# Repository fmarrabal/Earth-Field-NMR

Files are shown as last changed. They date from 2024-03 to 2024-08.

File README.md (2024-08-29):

# Earth Field NMR Spectrometer

This repository contains the complete design, schematics, PCB layout, microcontroller firmware, and computer software for an Earth Field Nuclear Magnetic Resonance (EFNMR) spectrometer. This device is designed to operate using the Earth's magnetic field, providing a cost-effective and accessible NMR solution for educational and research purposes.

## Overview

Nuclear Magnetic Resonance (NMR) is a powerful analytical technique used to study the physical, chemical, and biological properties of matter. Conventional NMR spectrometers require high magnetic fields, making them expensive and limited to specialized laboratories. The Earth Field NMR (EFNMR) spectrometer, however, utilizes the Earth's magnetic field, significantly reducing the cost and complexity of the device.

This project aims to develop an EFNMR spectrometer that can be used for educational purposes, allowing students and researchers to gain hands-on experience with NMR technology without the need for high-field NMR equipment.

## Components

The EFNMR spectrometer consists of the following main components:

1. **Polarizing Coil**
   - Generates a temporary magnetic field to polarize the sample.
   - Specifications:
     - Enamelled copper wire: 1.7 mm or 14 AWG
     - Inner diameter: 80 mm
     - Outer diameter: 90 mm
     - Height: 145 mm
     - Approximate inductance: 3.4 mH
     - Approximate resistance: 0.8 Ω

2. **Receiver Coils (Antenna)**
   - Detects the signal from the polarized sample.
   - Specifications:
     - Enamelled copper wire: 0.812 mm or 21 AWG
     - Inner diameter: 25 mm
     - Outer diameter: 40 mm
     - Height: 100 mm
     - Approximate inductance per coil: 2.56 mH
     - Approximate resistance per coil: 2.5 Ω

3. **Power Circuit**
   - Controls the power supply to the polarizing coil.
   - Utilizes a MOSFET for fast switching and high current handling.

4. **Receiver Circuit**
   - Amplifies and filters the weak NMR signal from the receiver coils.
   - Consists of a low-noise instrumentation amplifier, additional amplification stages, and a band-pass filter.

5. **Microcontroller (STM32F373)**
   - Handles control tasks, signal digitization, and communication with a computer.
   - Features a 16-bit ADC and USB communication.

6. **Computer Software**
   - Provides a user interface for configuring experiments, visualizing results, and performing signal processing.
   - Developed in C# for ease of use and rapid implementation of new features.

## Usage

To use the EFNMR spectrometer, follow these steps:

1. **Assemble the Hardware**
   - Ensure all components are correctly assembled and connected as per the provided schematics and PCB layout.

2. **Upload the Firmware**
   - Program the STM32F373 microcontroller with the provided firmware.

3. **Install the Software**
   - Install the computer software on a compatible system.

4. **Perform an Experiment**
   - Use the software to configure the experimental parameters (e.g., number of samples, number of scans, pulse time).
   - Align the coils with the Earth's magnetic field using the built-in magnetometer.
   - Start the experiment and visualize the results in the software.

## Repository Contents

- `PCB/`: PCB layout files for manufacturing the PCBs.
- `Firmware/`: Source code for the microcontroller firmware.
- `EFMNR/`: Source code and binaries for the computer software.
- `Assembly/`: CAD designs for 3D printed parts used in the spectrometer assembly.

## Acknowledgements

This project was developed at the University of Almeria, Spain. Also, The research received generous funding from the following sources:
- the State Research Agency of the Spanish Ministry of Science and Innovation (PID2021-126445OB-I00)
- the Gobierno de España MCIN/AEI/10.13039 /501100011033
- European Union “Next Generation EU”/PRTR (PDC2021-121248-I00, PLEC2021- 007774 and CPP2022-009967).

We extend our heartfelt gratitude to all the contributors who played a vital role in making this project a reality.

## Reference

Please cite this project using the following BibTeX entry:

@article{Viciana2024,
author = {Viciana, Eduardo and Mart{\'{i}}nez-Lao, Juan Antonio and L{\'{o}}pez-Lao, Emilio and Fern{\'{a}}ndez, Ignacio and Arrabal-Campos, Francisco Manuel},
doi = {10.3390/s24175537},
issn = {1424-8220},
journal = {Sensors},
keywords = {earth,efnmr,nmr spectrometer,s field nmr},
month = {aug},
number = {17},
pages = {5537},
title = {{Development of an Earth-Field Nuclear Magnetic Resonance Spectrometer: Paving the Way for AI-Enhanced Low-Field Nuclear Magnetic Resonance Technology}},
url = {https://www.mdpi.com/1424-8220/24/17/5537},
volume = {24},
year = {2024}
}

## Contact

For questions or further information, please contact fmarrabal@ual.es

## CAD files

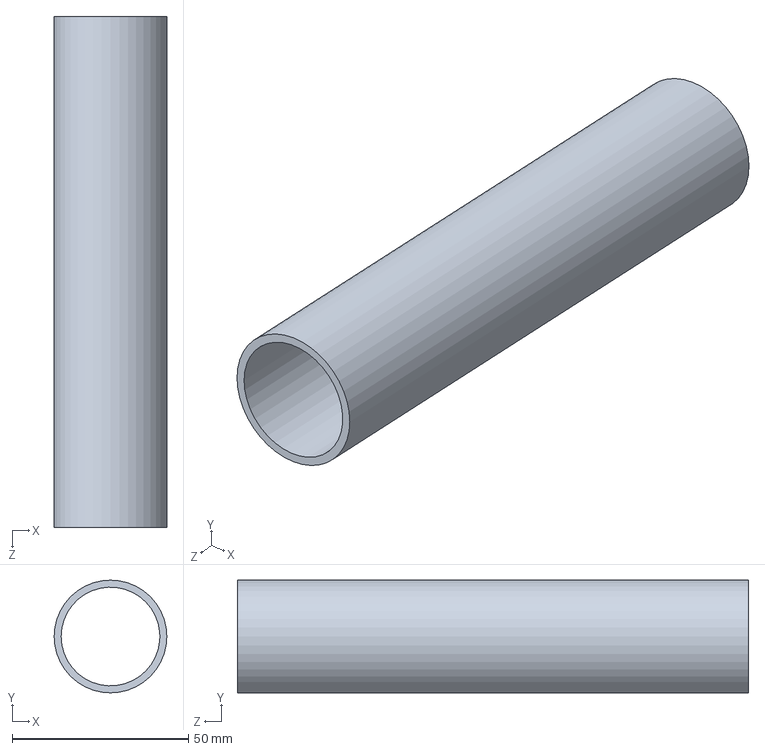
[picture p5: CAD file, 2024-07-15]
Assembly/Receiver coil.SLDPRT
32.0 x 32.0 x 145.0 mm

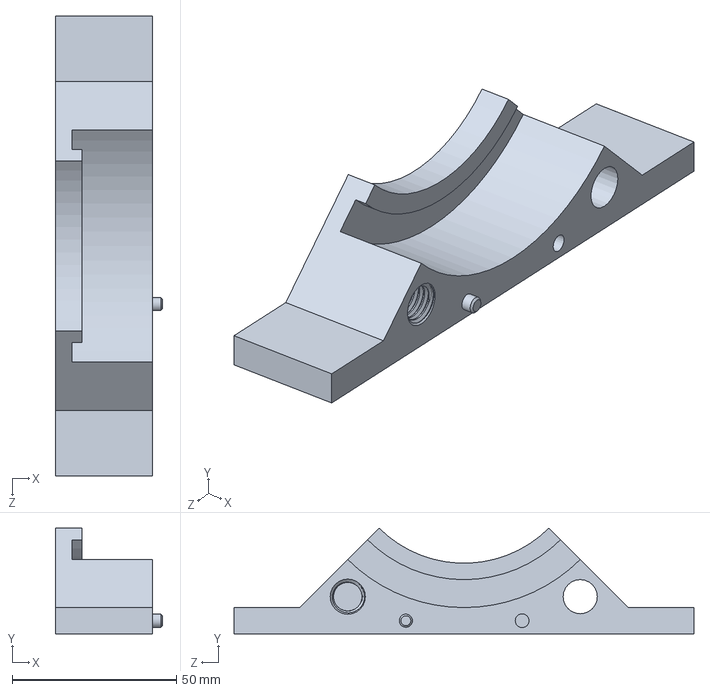
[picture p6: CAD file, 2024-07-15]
Assembly/Base.SLDPRT
32.5 x 32.2 x 140.0 mm

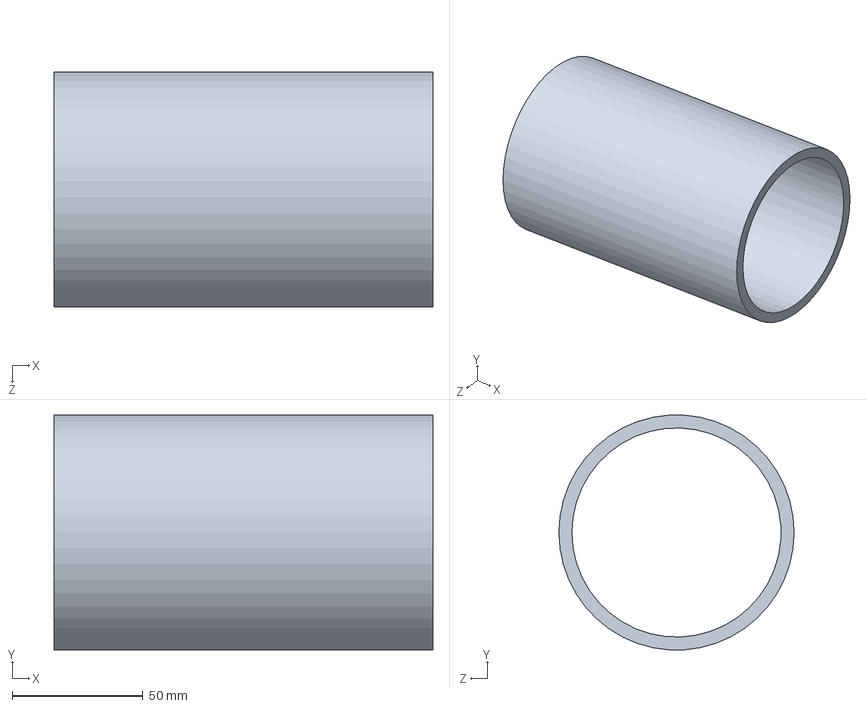
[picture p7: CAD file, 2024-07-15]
Assembly/Excitation coil.SLDPRT
145.0 x 89.8 x 90.0 mm

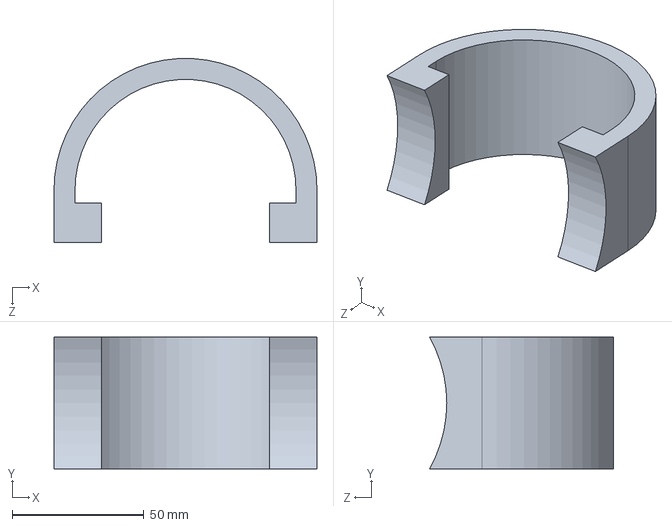
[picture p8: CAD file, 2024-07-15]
Assembly/Inclination support.SLDPRT
100.0 x 50.0 x 69.9 mm

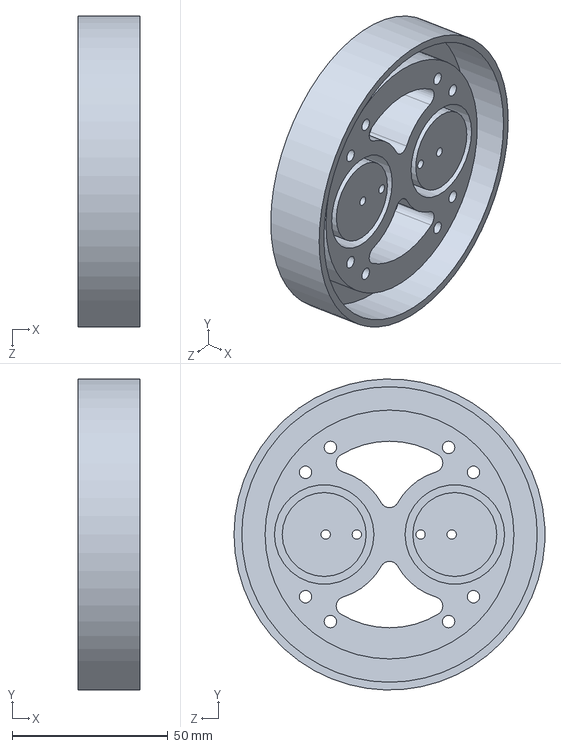
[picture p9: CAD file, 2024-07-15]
Assembly/Coil support.SLDPRT
20.0 x 100.0 x 100.0 mm

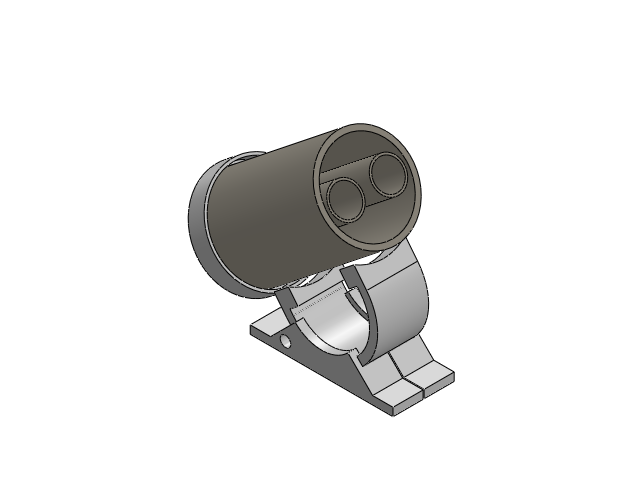
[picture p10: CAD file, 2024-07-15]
Assembly/Assembly.SLDASM
Soporte bobinas
Bobina Externa
Base x 2
Soporte Inclinacion
bobina RX x 2

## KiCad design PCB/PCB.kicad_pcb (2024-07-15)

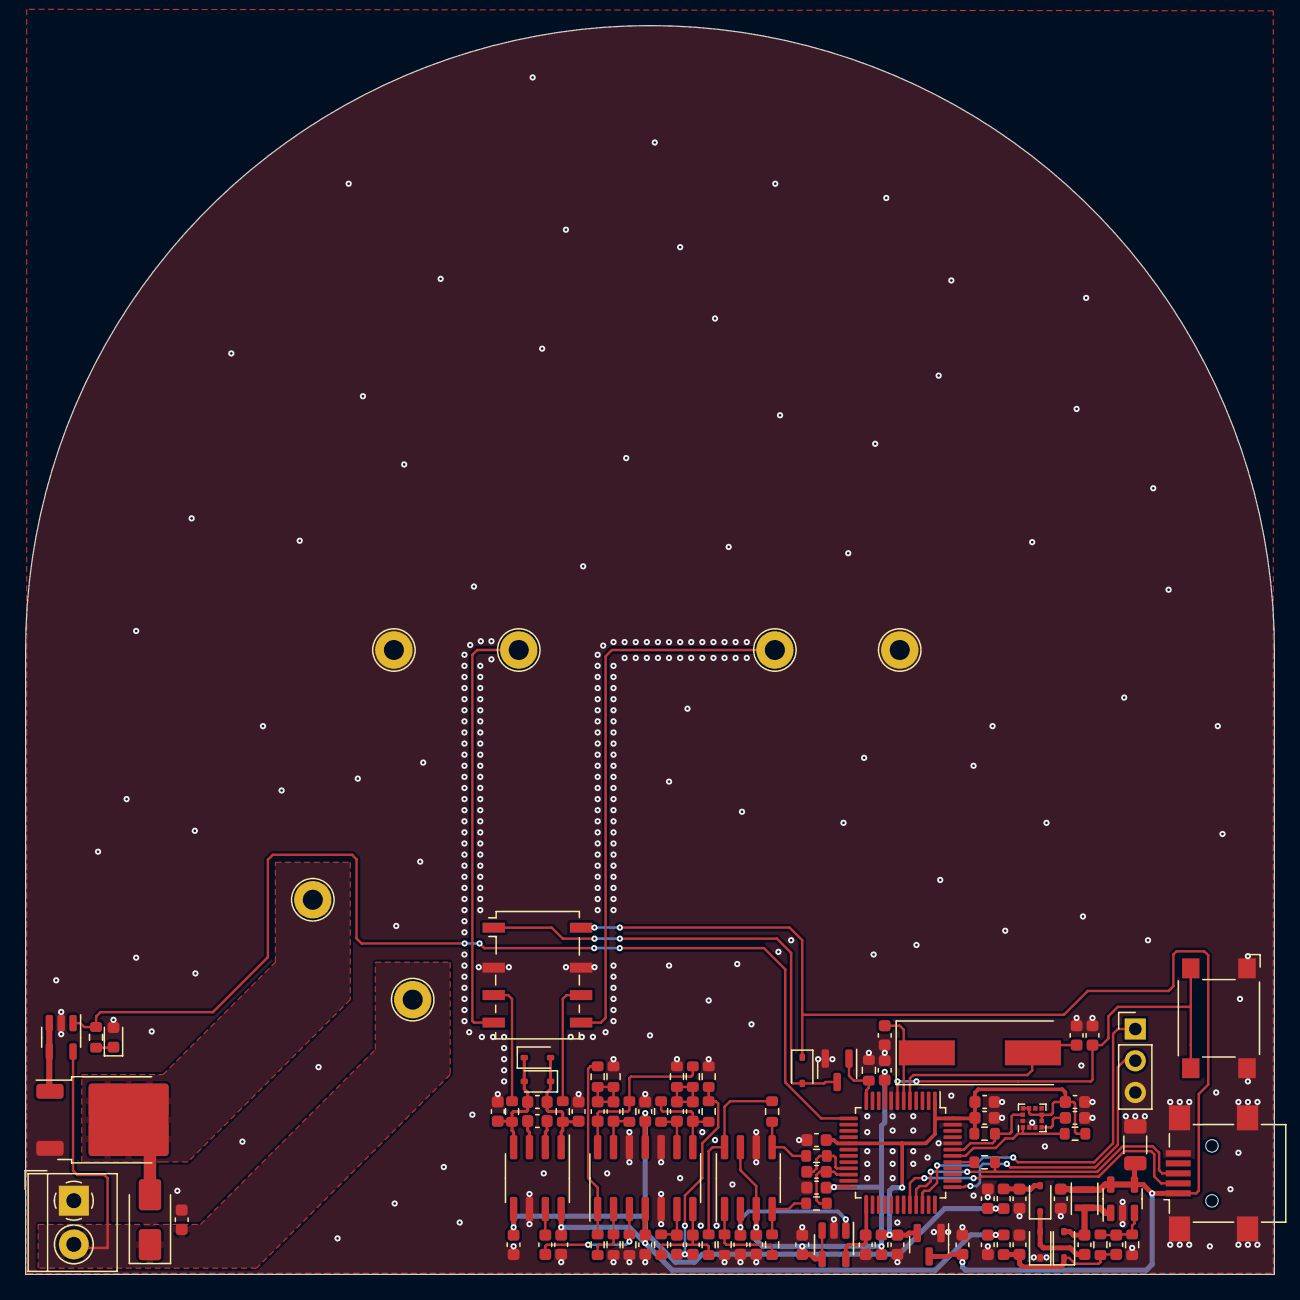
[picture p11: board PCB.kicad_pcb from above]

Board: 2 copper layers, 100.0 x 100.0 mm, 103 parts (0 on the bottom side), 58 nets.

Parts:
C1: 100uF; C_1206_3216Metric
C2, C3, C4, C6, C7, C8, C11, C12, C13, C19, C25, C38, C39: 100nF; C_0603_1608Metric
C5, C15, C16, C23, C24: 1uF; C_0603_1608Metric
C9, C10: 12pF; C_0603_1608Metric
C14: 120pF; C_0603_1608Metric
C17, C18, C26, C27, C28, C29, C30, C31, C32, C33, C34, C40: C_Small; C_0603_1608Metric
C20, C21: 10nF; C_0603_1608Metric
C22: 220pF; C_0603_1608Metric
C35, C36, C37, C41: CC0603KRX7R9BB104; C_0603_1608Metric
D1: SMAJ45A; D_SMA
D2: LED; LED_0603_1608Metric
D3, D4, D5: SD103AWS-7-F; D_SOD-323
D6, D7: SD101A; D_SOD-323
D8: 1.5KExxA; D_SOD-323
FB1, FB2, FB3: FerriteBead_Small; L_0603_1608Metric
J1: USB_B_Mini; USB_Mini-B_Lumberg_2486_01_Horizontal
J2: Screw_Terminal_01x02; TerminalBlock_4Ucon_1x02_P3.50mm_Horizontal
J3: Conn_01x03; PinHeader_1x03_P2.54mm_Vertical
K1: G6K-2; Relay_DPDT_Omron_G6K-2F-Y
L1: CBC3225T100KR; L_Murata_DFE201610P
Q1: IPD50R3K0CE; TO-252-2
Q2: 2N7002; SOT-23
R1: 1k5; R_0603_1608Metric
R2, R3: 4k7; R_0603_1608Metric
R4, R6, R11, R12, R13, R14, R15, R16, R17, R18, R19, R20, R21, R22, R23, R24, R25, R26, R28: R_Small; R_0603_1608Metric
R7: 15k; R_0603_1608Metric
R8: 150k; R_0603_1608Metric
R9, R10: 49.9h; R_0603_1608Metric
R27: R_0603_1608Metric
SW1: SW_Omron_B3FS; SW_SPST_Omron_B3FS-100xP
TP1, TP2, TP3, TP4, TP5, TP6: TestPoint; TestPoint_Loop_D2.60mm_Drill1.6mm_Beaded
U1: STM32F373C8Tx; LQFP-48_7x7mm_P0.5mm
U2: LIS3MDL; LGA-12_2x2mm_P0.5mm
U3: INA848; SOIC-8_3.9x4.9mm_P1.27mm
U4: LM27313XMFX/NOPB; SOT-23-5
U5: OPA4189xD; SOIC-14_3.9x8.7mm_P1.27mm
U6: THS4561; SOIC-8_3.9x4.9mm_P1.27mm
U7: UCC44273; SOT-23-5
U8: REF2025AIDDCR; SOT-23-5
U9: MCP1700-3.3; SOT-23
Y1: 8MHz; Crystal_SMD_HC49-SD

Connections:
1.25V_{REF}: C36.1, U6.2 (V_{OCM}), U8.1 (Vbias)
2.5V_{REF}: C35.2, U1.25 (VREFSD+), U8.5 (Vref)
3.3V: C2.2, C3.1, C5.1, C6.1, C38.2, FB1.1, R2.1, R3.1, U1.1 (VBAT), U1.17 (VDD), U1.48 (VDD), U2.5 (Vdd), U2.6 (Vdd_IO), U2.9 (SDO/SA1), U2.10 (~CS), U9.2 (VOUT)
3.3V_{A}: C4.1, C7.1, C34.1, C37.2, FB1.2, U1.9 (VDDA), U1.24 (VDDSD), U6.3 (V_{S+}), U6.7 (~PD), U8.3 (EN), U8.4 (VIN)
5V: C1.1, C12.1, C39.2, D8.1 (A1), J1.1 (VBUS), K1.8, L1.1, U4.4 (EN), U4.5 (VIN), U9.3 (VIN)
12V: C17.1, C23.1, C33.1, FB2.2, U3.8 (Vs+), U5.4 (V+)
-12V: C18.1, C24.2, C32.1, FB3.2, U3.5 (Vs-), U5.11 (V-)
ADC+: R24.2, R27.1, U6.5
ADC-: R25.2, R28.1, U6.4
EN_{B}: R6.1, U1.13 (PA3), U7.1 (IN)
EN_{Relay}: Q2.1 (G), R4.1, U1.12 (PA2)
GNDD: C1.2, C2.1, C3.2, C4.2, C5.2, C6.2, C7.2, C8.2, C9.1, C10.1, C11.2, C12.2, C15.2, C16.1, C17.2, C18.2, C20.1, C21.2, C23.2, C24.1, C32.2, C33.2, C34.2, C35.1, C36.2, C37.1, C38.1, C39.1, C41.2, D2.2 (A), D4.1 (K), J1.5 (GND), J1.6 (Shield), J2.1, J3.3, K1.2, K1.7, Q1.3 (S), Q2.2 (S), R4.2, R7.2, R11.2, R12.2, R16.1, R18.1, R21.1, R26.1, SW1.1, TP2.1, TP6.1, U1.8 (VSSA), U1.23 (VSSSD), U1.44 (BOOT0), U1.47 (VSS), U2.2 (GND), U2.3 (GND), U2.12 (GND), U3.6 (Ref), U4.2 (GND), U5.5 (+), U5.10 (+), U5.12 (+), U6.6 (V_{S-}), U7.2 (GND), U8.2 (GND), U9.1 (GND)
unnamed: C22.1, U3.2 (Rg)
unnamed: C22.2, U3.3 (Rg)
unnamed: C25.1, U3.7
unnamed: C26.1, C27.1, R14.2, R16.2
unnamed: C27.2, R15.2, R17.1, U5.14
unnamed: C28.1, C29.1, R17.2, R18.2
unnamed: C28.2, R19.2, R20.1, U5.8
unnamed: C30.1, C31.1, R20.2, R21.2
unnamed: C30.2, R22.2, R23.1, U5.7
unnamed: C41.1, D1.1 (A1), J2.2, TP4.1, U7.5 (Vdd)
unnamed: D1.2 (A2), Q1.2 (D), TP5.1
unnamed: D2.1 (K), R6.2
unnamed: C13.1, D3.2 (A), L1.2, U4.1 (SW)
unnamed: C14.1, C15.1, D3.1 (K), FB2.1, R8.1
unnamed: C13.2, D4.2 (A), D5.1 (K)
unnamed: C16.2, D5.2 (A), FB3.1
unnamed: C19.2, C21.1, D6.2 (A), D7.1 (A1), R10.1, U3.4 (+)
unnamed: C19.1, C20.2, D6.1 (K), D7.2 (A2), R9.1, U3.1 (-)
unnamed: D8.2 (A2), K1.1, Q2.3 (D)
unnamed: J1.3 (D+), R1.2, U1.33 (PA12)
unnamed: J1.2 (D-), U1.32 (PA11)
unnamed: J3.1, U1.34 (PA13)
unnamed: J3.2, U1.37 (PA14)
unnamed: K1.3, R10.2
unnamed: K1.4, TP3.1
unnamed: K1.5, TP1.1
unnamed: K1.6, R9.2
unnamed: Q1.1 (G), U7.3 (OUT), U7.4 (OUT)
unnamed: R13.2, R14.1, U5.1
unnamed: C8.1, SW1.2, U1.7 (NRST)
unnamed: R1.1, U1.41 (PB5)
unnamed: C40.1, R27.2, U1.21 (PE8)
unnamed: C40.2, R28.2, U1.22 (PE9)
unnamed: C9.2, U1.5 (PF0), Y1.2
unnamed: C10.2, U1.6 (PF1), Y1.1
unnamed: C11.1, U2.4 (C1)
unnamed: C14.2, R7.1, R8.2, U4.3 (FB)
unnamed: C25.2, R11.1, U5.3 (+)
unnamed: R12.1, R13.1, U5.2 (-)
unnamed: C31.2, R22.1, U5.6 (-)
unnamed: C29.2, R19.1, U5.9 (-)
unnamed: C26.2, R15.1, U5.13 (-)
unnamed: R23.2, R24.1, U6.8 (+)
unnamed: R25.1, R26.2, U6.1 (-)
SCL: R2.2, U1.42 (PB6), U2.1 (SCL/SPC)
SDA: R3.2, U1.43 (PB7), U2.11 (SDA/SDI/SDO)

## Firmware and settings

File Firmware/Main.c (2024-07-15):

#include "Main.h"
// ---------------------------------------------------------------------------------------------------------------------
static          uint8_t  PreDelay;
static          uint8_t  PostDelay;
static          uint16_t PulseLen;
static          uint16_t RecoveryLen;
static          uint32_t Samples;
static volatile uint16_t Scans;
// ---------------------------------------------------------------------------------------------------------------------
uint8_t Int2Hex(const char ch) {                                                //Convert binary to hex character
  return (ch < 10) ? ch + '0' : 'A' + ch - 10;                                  //
}                                                                               //
// --------------------------------------------------------------------------------------------------------------------
void SetTimes(const uint16_t pulse, const uint16_t recovery) {
  if(Scans != 0) return;
  PulseLen = pulse;
  RecoveryLen = recovery;
}
void SetDelays(const uint16_t predelay, const uint16_t posdelay) {
  if(Scans != 0) return;
  PreDelay = predelay;
  PostDelay = posdelay;
}
void SetSamples(const uint32_t samples) {
  if(Scans != 0) return;
  Samples = samples;
}
void Capture(const uint16_t scans) {
  if(Scans != 0) return;
  BUFF_Init();                                                              //Clear buffer
  Scans = scans;
}
// --------------------------------------------------------------------------------------------------------------------
void TIM6Delay(const uint16_t ms) {                                             //Basic delay
  TIM6->CNT = 0;                                                                //reset count
  TIM6->ARR = ms << 1;                                                          //
  TIM6->CR1 = TIM_CR1_OPM | TIM_CR1_CEN;                                        //Start timer
  while ((TIM6->CR1 & TIM_CR1_CEN) != 0);                                         //Wait
  TIM6->SR &= ~TIM_SR_UIF;                                                      //Clear interrupt
}                                                                               //
// --------------------------------------------------------------------------------------------------------------------
void Main() {                                                                   //Entry point
  RCC->APB1ENR |= RCC_APB1ENR_TIM6EN;                                           //Enable used periperals
  RCC->AHBENR |= RCC_AHBENR_GPIOAEN;                                            //
  GPIOA->MODER |= (0b01<<GPIO_MODER_MODER2_Pos)|(0b01<<GPIO_MODER_MODER3_Pos);  //Configure ports
  TIM6->PSC = (AHB_CLK / 2000) - 1;                                             //Tim 6 prescaler (0.5ms ticks)
  TIM6Delay(200);
  BUFF_Init();                                                                  //Init buffer
  SDADC_Init();                                                                 //Init ADC
  USB_Init();                                                                   //Init USB
  while(true) {                                                                 //repeat forever
    if(Scans != 0) {                                                            //If pending scans
      GPIOA->BSRR = GPIO_BSRR_BS_3;                                             //Enable polarize coil
      TIM6Delay(PulseLen);                                                      //Wait
      GPIOA->BSRR = GPIO_BSRR_BR_3;                                             //Disable polarize coil
      TIM6Delay(PreDelay);                                                      //Wait
      GPIOA->BSRR = GPIO_BSRR_BS_2;                                             //Enable relay
      TIM6Delay(PostDelay);                                                     //Wait
      SDADC_Capture(Samples);                                                   //Start capture
      GPIOA->BSRR = GPIO_BSRR_BR_2;                                             //Disable relay
      TIM6Delay(RecoveryLen);                                                   //Wait
      Scans--;                                                                  //
      BUFF_IncScan();                                                           //Move to next scan
    }                                                                           //
  }                                                                             //
}                                                                               //
// --------------------------------------------------------------------------------------------------------------------

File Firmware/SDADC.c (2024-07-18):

#include "Main.h"
// ---------------------------------------------------------------------------------------------------------------------
static uint16_t          Buffer[64];                                            //SDADC1 buffer
static volatile uint32_t Samples;                                               //Pending samples to capture
// ---------------------------------------------------------------------------------------------------------------------
void DMA2_CH3_ISR() {                                                           //Handle DMA interrupt
  uint16_t *Ptr;                                                                //
  if((DMA2->ISR & DMA_ISR_TCIF3) != 0) {                                        //Prepare Trasnfer complete
    DMA2->IFCR |= DMA_IFCR_CTCIF3;                                              //Interrupt clear
    Ptr = &Buffer[32];                                                          //Init pointer
  } else {                                                                      //Prepare half transfer
    DMA2->IFCR |= DMA_IFCR_CHTIF3;                                              //Interrupt clear
    Ptr = &Buffer[0];                                                           //Init pointer
  }                                                                             //
  if(Samples == 0) {                                                            //If no more samples
    SDADC1->CR2 &= ~SDADC_CR2_RCONT;                                            //Disable SDADC
    DMA2_Channel3->CCR = 0;                                                     //Reset DMA
  } else {                                                                      //
    for(uint8_t n = 0; n < 32; n++) BUFF_PushSample(*Ptr++);                    //Copy sample
    Samples = Samples - 32;                                                     //Decrement counter
  }                                                                             //
}                                                                               //
void SDADC_Capture(const uint32_t samples) {                                    //Init capture
  Samples = samples & 0xFFFFFFE0;                                               //Round to 32
  DMA2->IFCR |= DMA_IFCR_CTCIF3 | DMA_IFCR_CHTIF3;                              //Interrupt clear
  DMA2_Channel3->CPAR = (uint32_t)&SDADC1->RDATAR;                              //Initialize SDADC1 DMA controller
  DMA2_Channel3->CMAR = (uint32_t)Buffer;                                       //
  DMA2_Channel3->CNDTR = 64;                                                    //
  DMA2_Channel3->CCR = DMA_CCR_MSIZE_0|DMA_CCR_PSIZE_0|DMA_CCR_EN |             //
                       DMA_CCR_CIRC|DMA_CCR_MINC|DMA_CCR_TCIE|DMA_CCR_HTIE;     //
  SDADC1->CR2 |= SDADC_CR2_RCONT | SDADC_CR2_RSWSTART;                          //Start conversion
  while(Samples != 0);                                                          //Wait for ADC to complete
}                                                                               //
void SDADC_Init() {                                                             //Init ADCs capture
  RCC->AHBENR |=  RCC_AHBENR_DMA2EN  | RCC_AHBENR_GPIOEEN;                      //Enable used devices in AHB
  RCC->APB1ENR |= RCC_APB1ENR_PWREN;                                            //
  PWR->CR |= PWR_CR_SDADC1EN;                                                   //Enable SDADC power
  RCC->APB2ENR |= RCC_APB2ENR_SYSCFGEN | RCC_APB2ENR_SDADC1EN;                  //Enable OPAMPs and used timers
  GPIOE->MODER |= (0b11<<GPIO_MODER_MODER8_Pos)|(0b11<<GPIO_MODER_MODER9_Pos);  //PE8=AN, PE9=AN
  SDADC1->CR2 |= SDADC_CR2_ADON;                                                //Enable SDADC
  while((SDADC1->ISR & SDADC_ISR_STABIP) != 0);                                 //Wait for stabilization
  SDADC1->CR1 |= SDADC_CR1_INIT;                                                //Initialization
  while((SDADC1->ISR & SDADC_ISR_INITRDY) == 0);                                //Wait initialization bit to be set
  SDADC1->CR1 |= SDADC_CR1_RDMAEN;                                              //Enable DMA
  SDADC1->CR2 |= SDADC_CR2_FAST | (0b1000 << SDADC_CR2_RCH_Pos);                //Config capture channel and mode
  SDADC1->CR1 &= ~SDADC_CR1_INIT;                                               //Exit initialization mode
  SDADC1->CR2 |= SDADC_CR2_STARTCALIB;                                          //Start calibration
  while((SDADC1->ISR & SDADC_ISR_CALIBIP) != 0);                                //Wait calibration to finish
  NVIC_SetPriority(DMA2_Channel3_IRQn, 0);                                      //Set interrupts priority and enable then
  NVIC_EnableIRQ(DMA2_Channel3_IRQn);                                           //

//  ADC12_COMMON->CCR = ADC12_CCR_CKMODE_0 | ADC12_CCR_MDMA_1 |                   //Configure dual mode and clock source
//                      ADC12_CCR_DMACFG | ADC12_CCR_MULTI_0;                     //
//  ADC34_COMMON->CCR = ADC34_CCR_CKMODE_0 | ADC34_CCR_MDMA_1 |                   //
//                      ADC34_CCR_DMACFG | ADC34_CCR_MULTI_0;                     //
//  ADC1->CR = 0;                                                                 //Enable ADCs VREF (First step)
//  ADC1->CR = ADC_CR_ADVREGEN_0;                                                 //
//  ADC2->CR = 0;                                                                 //
//  ADC2->CR = ADC_CR_ADVREGEN_0;                                                 //
//  ADC3->CR = 0;                                                                 //
//  ADC3->CR = ADC_CR_ADVREGEN_0;                                                 //
//  ADC4->CR = 0;                                                                 //
//  ADC4->CR = ADC_CR_ADVREGEN_0;                                                 //
//  SystickDelay(1000);                                                           //Wait for ADCs VREF to stabilize
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

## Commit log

2024-03-26 PRIMERA SUBIDA DE ARCHIVOS
    Este código es el que se ha programado para el TFG de Emilio
2024-04-14 Añadido el PCB y Firmware. El PCB va, aunque tengo que meter una pista que falta que ahora esta con un cable. El firmware se conecta al PC, pero no hace lo que deberia de momento por que es de otro p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
    [PCB-B_Cu.gbr, PCB-B_Mask.gbr, PCB-B_Paste.gbr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]
